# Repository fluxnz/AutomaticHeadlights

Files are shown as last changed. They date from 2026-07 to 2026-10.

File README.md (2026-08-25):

# Automatic Headlights (Arduino Nano)

Automatic headlight controller for an Arduino Nano using a BH1750 ambient light sensor, OLED status display, manual override switch, and relay output.

## Features

- Automatic relay control from ambient light (lux)
- Potentiometer-adjustable AUTO threshold (`0` to `400` lux)
- Hysteresis plus ON/OFF delay to prevent relay chatter
- Fail-safe behavior:
  - Relay stays OFF if the BH1750 sensor fails to initialize or returns an invalid reading
  - Relay logic continues even if the OLED is disconnected or unavailable
- Manual override with SPDT center-off switch:
  - Force ON
  - AUTO (center)
  - Force OFF
- OLED UI with day/night icon and live values:
  - Mode (`AUTO` / `FORCE ON` / `FORCE OFF`)
  - `LUX` (live measured light)
  - `SET` (potentiometer threshold)
  - `LIGHT` (`ON` / `OFF` badge)

## Hardware

- Arduino Nano V3 USB-C (ATmega328PB)
- BH1750 GY-302 I2C light sensor
- SSD1306 0.96" OLED 128x64 I2C display
- 10k linear potentiometer (B10K)
- SPDT center-off toggle switch (ON-OFF-ON)
- 5V 1-channel relay module (SRD-05VDC-SL-C)
- 470uF electrolytic capacitor
- 100nF ceramic capacitor

## Wiring

### I2C bus

- Nano `A4` -> BH1750 `SDA` and OLED `SDA`
- Nano `A5` -> BH1750 `SCL` and OLED `SCL`
- Nano `5V` -> sensor/display `VCC`
- Nano `GND` -> sensor/display `GND`

### Inputs and output

- Potentiometer wiper -> Nano `A0`
- Pot ends -> `5V` and `GND`
- Relay input -> Nano `D8`
- Toggle switch common -> `GND`
- Toggle throw 1 -> Nano `D2` (force ON)
- Toggle throw 2 -> Nano `D3` (force OFF)
- Handbrake wire -> Nano `D4`
- Vehicle ground -> Nano `GND`

The sketch uses `INPUT_PULLUP` for the switch pins, so active switch position pulls pin `LOW`.
The handbrake input also uses `INPUT_PULLUP`, so when the handbrake wire is earthed, `D4` reads `LOW` (handbrake ON).

## Capacitor placement (recommended)

- `100nF` ceramic close to Nano `5V/GND`
- `470uF` electrolytic across `5V/GND` rail to absorb relay/supply transients

## Arduino sketch location

- `Sketch/AutomaticHeadlights/AutomaticHeadlights.ino`

## Required libraries

Install these libraries in Arduino IDE / Arduino CLI:

- `BH1750`
- `U8g2`

## Build and upload

1. Open `Sketch/AutomaticHeadlights/AutomaticHeadlights.ino` in Arduino IDE.
2. Select board: **Arduino Nano**.
3. Select the correct processor/bootloader settings for your Nano clone/original.
4. Select the correct COM port.
5. Compile and upload.

## Runtime behavior

- AUTO mode maps potentiometer value (`0-1023`) to `0-400` lux setpoint.
- Relay switches ON only after sustained darkness (`AUTO_ON_DELAY_MS`).
- Relay switches OFF only after sustained brightness (`AUTO_OFF_DELAY_MS`).
- Hysteresis (`HYSTERESIS_LUX`) prevents flicker near threshold.
- If the BH1750 sensor is unavailable or returns a bad reading, the sketch forces the relay OFF and disables AUTO control until reset.
- If the handbrake is ON (earthed input on `D4`), the sketch forces the relay OFF in all modes (AUTO / FORCE ON / FORCE OFF).
- Display rendering uses U8g2 page buffering (`_1_` constructor variant).

### Display example

AUTO  
Lux: 18 lx  
Set: 40 lx  
Brake: ON  
Light: OFF

## Safety note

This project is intended to switch a relay control signal. If you are switching vehicle lighting power, use proper automotive wiring practices (fusing, suitable wire gauge, and protected enclosures).

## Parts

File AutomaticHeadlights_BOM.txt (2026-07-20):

Arduino Nano
BH1750 GY-302 I2C Light Sensor Module
SSD1306 0.96" OLED 128x64 I2C Display
10k Linear Potentiometer (B10K)
SPDT Centre-Off Toggle Switch (ON-OFF-ON)
5V 1-Channel Relay Module (SRD-05VDC-SL-C)
470µF 16V Electrolytic Capacitor
100nF Ceramic Capacitor

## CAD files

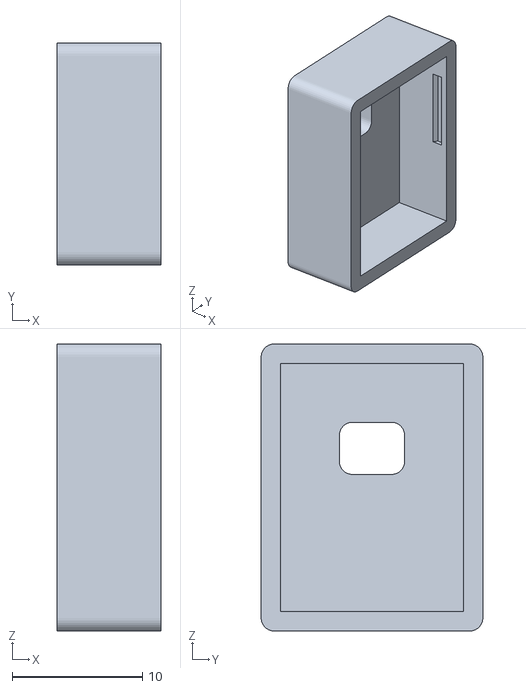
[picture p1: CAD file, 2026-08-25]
BH1750_Case_Base.stl
8.00 x 17.0 x 22.0

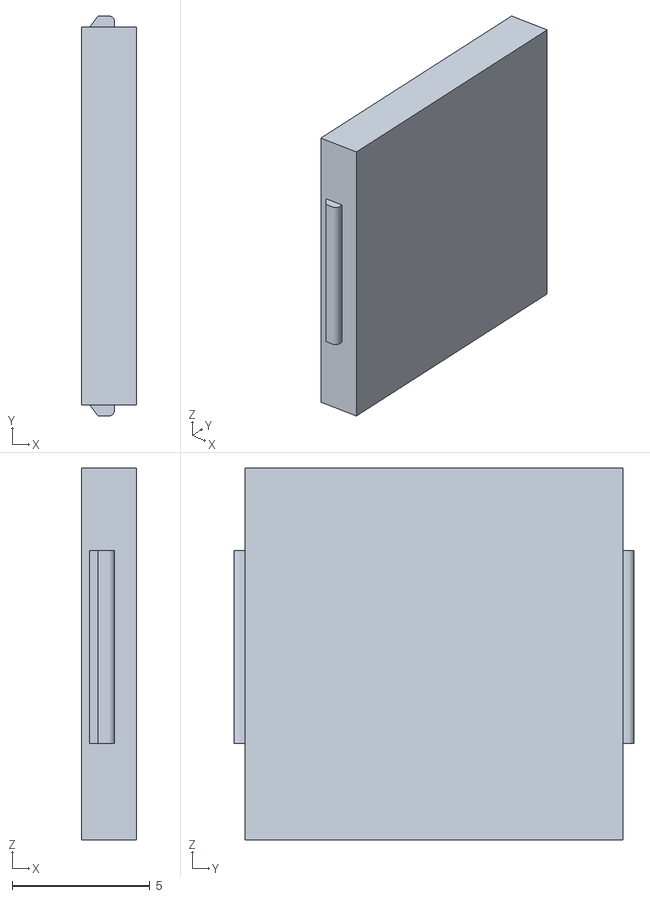
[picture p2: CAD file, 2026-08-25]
BH1750_Case_Base_Lid.stl
2.00 x 14.5 x 13.5

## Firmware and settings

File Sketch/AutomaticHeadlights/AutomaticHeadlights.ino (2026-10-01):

#include <Wire.h>
#include <BH1750.h>
#include <U8g2lib.h>

// -------- Hardware configuration --------
static const uint8_t PIN_RELAY = 8;
static const uint8_t PIN_POT = A0;
static const uint8_t PIN_SWITCH_FORCE_ON = 2;
static const uint8_t PIN_SWITCH_FORCE_OFF = 3;
static const uint8_t PIN_HANDBRAKE = 4;

// Most 5V relay modules are active LOW. Set false if your module is active HIGH.
static const bool RELAY_ACTIVE_LOW = true;

// OLED (128x64, I2C)
U8G2_SSD1306_128X64_NONAME_1_HW_I2C display(U8G2_R0);

BH1750 lightMeter;

enum ControlMode {
	MODE_AUTO,
	MODE_FORCE_ON,
	MODE_FORCE_OFF
};

float currentLux = 0.0f;
float filteredLux = 0.0f;
bool relayClosed = false;  // Closed = headlights ON.
bool displayReady = false;
bool sensorReady = false;
bool hasLuxSample = false;

unsigned long lastSensorReadMs = 0;
unsigned long lastDisplayRefreshMs = 0;
unsigned long darkCandidateStartMs = 0;
unsigned long brightCandidateStartMs = 0;
unsigned long lastSensorReinitAttemptMs = 0;
unsigned long lastI2cRecoveryMs = 0;
uint8_t consecutiveSensorErrors = 0;

static const uint16_t SENSOR_INTERVAL_MS = 200;
static const uint16_t DISPLAY_INTERVAL_MS = 120;
static const uint16_t AUTO_ON_DELAY_MS = 2500;
static const uint16_t AUTO_OFF_DELAY_MS = 4000;
static const uint16_t SENSOR_REINIT_INTERVAL_MS = 1500;
static const uint16_t I2C_RECOVERY_INTERVAL_MS = 10000;
static const uint8_t MAX_SENSOR_ERRORS_BEFORE_FAULT = 5;

// Map potentiometer (0..1023) to an easy-to-tune AUTO trigger range.
// Left 0 lx (very dark), center ~200 lx, right 400 lx.
static const float THRESHOLD_MIN_LUX = 0.0f;
static const float THRESHOLD_MAX_LUX = 400.0f;

// Hysteresis band to avoid relay chatter around threshold.
static const float HYSTERESIS_LUX = 35.0f;

// BH1750 high-res mode tops out well below this; anything above is a bad reading.
static const float MAX_VALID_LUX = 60000.0f;

void resetAutoTimers() {
	darkCandidateStartMs = 0;
	brightCandidateStartMs = 0;
}

void forceRelayOpenAndReset() {
	writeRelay(false);
	resetAutoTimers();
}

void writeRelay(bool closed) {
	relayClosed = closed;
	uint8_t pinState;
	if (RELAY_ACTIVE_LOW) {
		pinState = closed ? LOW : HIGH;
	} else {
		pinState = closed ? HIGH : LOW;
	}
	digitalWrite(PIN_RELAY, pinState);
}

ControlMode readModeFromSwitch() {
	// Switch expected wiring:
	// - Common to GND
	// - One throw to D2 (force ON), other throw to D3 (force OFF)
	// - Center OFF leaves both pins HIGH via INPUT_PULLUP
	bool forceOnActive = digitalRead(PIN_SWITCH_FORCE_ON) == LOW;
	bool forceOffActive = digitalRead(PIN_SWITCH_FORCE_OFF) == LOW;

	if (forceOnActive && !forceOffActive) {
		return MODE_FORCE_ON;
	}
	if (forceOffActive && !forceOnActive) {
		return MODE_FORCE_OFF;
	}
	return MODE_AUTO;
}

bool isHandbrakeOn() {
	// Handbrake wire is expected to be earthed when engaged.
	// With INPUT_PULLUP, LOW means handbrake ON.
	return digitalRead(PIN_HANDBRAKE) == LOW;
}

float readThresholdFromPot() {
	int pot = analogRead(PIN_POT);
	return THRESHOLD_MIN_LUX +
				 (THRESHOLD_MAX_LUX - THRESHOLD_MIN_LUX) * (static_cast<float>(pot) / 1023.0f);
}

void updateAutoRelayWithDelay(unsigned long now, float thresholdLux) {
	float onTriggerLux = thresholdLux - HYSTERESIS_LUX;
	float offTriggerLux = thresholdLux + HYSTERESIS_LUX;
	if (onTriggerLux < 0.0f) {
		onTriggerLux = 0.0f;
	}

	if (!relayClosed) {
		// Open relay (lights OFF): require sustained dark before turning ON.
		if (currentLux < onTriggerLux) {
			if (darkCandidateStartMs == 0) {
				darkCandidateStartMs = now;
			}
			if (now - darkCandidateStartMs >= AUTO_ON_DELAY_MS) {
				writeRelay(true);
				darkCandidateStartMs = 0;
			}
		} else {
			darkCandidateStartMs = 0;
		}
		brightCandidateStartMs = 0;
	} else {
		// Closed relay (lights ON): require sustained bright before turning OFF.
		if (currentLux > offTriggerLux) {
			if (brightCandidateStartMs == 0) {
				brightCandidateStartMs = now;
			}
			if (now - brightCandidateStartMs >= AUTO_OFF_DELAY_MS) {
				writeRelay(false);
				brightCandidateStartMs = 0;
			}
		} else {
			brightCandidateStartMs = 0;
		}
		darkCandidateStartMs = 0;
	}
}

void drawSunIcon(int16_t cx, int16_t cy) {
	display.setDrawColor(1);
	display.drawDisc(cx, cy, 7);
	display.setDrawColor(0);
	display.drawDisc(cx, cy, 4);
	display.setDrawColor(1);
	for (uint8_t i = 0; i < 8; i++) {
		float a = i * 0.785398f;  // 2*pi/8
		int16_t x0 = cx + static_cast<int16_t>(9 * cos(a));
		int16_t y0 = cy + static_cast<int16_t>(9 * sin(a));
		int16_t x1 = cx + static_cast<int16_t>(13 * cos(a));
		int16_t y1 = cy + static_cast<int16_t>(13 * sin(a));
		display.drawLine(x0, y0, x1, y1);
	}
}

void drawMoonIcon(int16_t cx, int16_t cy) {
	display.setDrawColor(1);
	display.drawDisc(cx, cy, 8);
	display.setDrawColor(0);
	display.drawDisc(cx + 4, cy - 2, 8);
	display.setDrawColor(1);
}

void drawUi(ControlMode mode, float thresholdLux) {
	bool handbrakeOn = isHandbrakeOn();
	display.firstPage();
	do {
		display.setDrawColor(1);
		display.setFont(u8g2_font_7x13B_tf);

		display.setCursor(0, 12);
		// Keep the active mode visible, and show brake status separately below.
		if (mode == MODE_FORCE_ON) {
			display.println(F("FORCE ON"));
		} else if (mode == MODE_FORCE_OFF) {
			display.println(F("FORCE OFF"));
		} else {
			display.println(F("AUTO"));
		}
		display.drawHLine(0, 14, 128);

		display.setFont(u8g2_font_6x12_tf);
		display.setCursor(0, 25);
		display.print(F("Lux: "));
		if (sensorReady) {
			float displayLux = constrain(currentLux, 0.0f, 32767.0f);
			display.print(static_cast<int>(displayLux + 0.5f));
			display.print(F(" lx"));
		} else {
			display.print(F("ERR"));
		}

		display.setCursor(0, 37);
		display.print(F("Set: "));
		display.print(static_cast<int>(thresholdLux + 0.5f));
		display.print(F(" lx"));

		display.setCursor(0, 49);
		display.print(F("Brake: "));
		display.print(handbrakeOn ? F("ON") : F("OFF"));

		display.setCursor(0, 61);
		display.print(F("Light: "));
		display.print(relayClosed ? F("ON") : F("OFF"));

		bool darkNow = currentLux < thresholdLux;
		if (darkNow) {
			drawMoonIcon(108, 34);
		} else {
			drawSunIcon(108, 34);
		}
	} while (display.nextPage());
}

void setup() {
	pinMode(PIN_RELAY, OUTPUT);
	pinMode(PIN_SWITCH_FORCE_ON, INPUT_PULLUP);
	pinMode(PIN_SWITCH_FORCE_OFF, INPUT_PULLUP);
	pinMode(PIN_HANDBRAKE, INPUT_PULLUP);

	// Fail-safe default: relay open at startup.
	forceRelayOpenAndReset();

	Wire.begin();
	// Prevent an I2C glitch from hanging the sketch forever.
	Wire.setWireTimeout(25000, true);
	sensorReady = lightMeter.begin(BH1750::CONTINUOUS_HIGH_RES_MODE);
	consecutiveSensorErrors = sensorReady ? 0 : MAX_SENSOR_ERRORS_BEFORE_FAULT;

	// U8g2 does not provide a simple init-fail status; begin and continue.
	display.begin();
	displayReady = true;
	display.firstPage();
	do {
		display.setDrawColor(1);
		display.setFont(u8g2_font_7x13B_tf);
		int16_t titleX = (128 - display.getStrWidth("Auto Headlights")) / 2;
		display.setCursor(titleX, 24);
		display.println(F("Auto Headlights"));
		display.setFont(u8g2_font_6x12_tf);
		int16_t initX = (128 - display.getStrWidth("Init...")) / 2;
		display.setCursor(initX, 42);
		display.println(F("Init..."));
	} while (display.nextPage());
}

void recoverI2cDevices() {
	// A short car supply glitch can leave I2C devices or the AVR bus in a bad state.
	// Reinitialize both devices periodically so the controller can recover without a power cycle.
	Wire.end();
	pinMode(A4, INPUT_PULLUP);
	pinMode(A5, INPUT_PULLUP);
	delay(10);
	Wire.begin();
	Wire.setWireTimeout(25000, true);

	sensorReady = lightMeter.begin(BH1750::CONTINUOUS_HIGH_RES_MODE);
	consecutiveSensorErrors = sensorReady ? 0 : MAX_SENSOR_ERRORS_BEFORE_FAULT;
	hasLuxSample = false;

	display.begin();
	displayReady = true;
}

void loop() {
	unsigned long now = millis();

	if (now - lastSensorReadMs >= SENSOR_INTERVAL_MS) {
		lastSensorReadMs = now;

		if (sensorReady) {
			float rawLux = lightMeter.readLightLevel();
			if (rawLux < 0.0f || isnan(rawLux) || isinf(rawLux) || rawLux > MAX_VALID_LUX) {
				if (consecutiveSensorErrors < 255) {
					consecutiveSensorErrors++;
				}
				if (consecutiveSensorErrors >= MAX_SENSOR_ERRORS_BEFORE_FAULT) {
					sensorReady = false;
					hasLuxSample = false;
					forceRelayOpenAndReset();
				}
			} else {
				consecutiveSensorErrors = 0;
				if (!hasLuxSample) {
					filteredLux = rawLux;
					hasLuxSample = true;
				} else {
					// Lightweight smoothing for stable display and control.
					filteredLux = (filteredLux * 0.75f) + (rawLux * 0.25f);
				}
				currentLux = filteredLux;
			}
		} else if (now - lastSensorReinitAttemptMs >= SENSOR_REINIT_INTERVAL_MS) {
			lastSensorReinitAttemptMs = now;
			sensorReady = lightMeter.begin(BH1750::CONTINUOUS_HIGH_RES_MODE);
			if (sensorReady) {
				consecutiveSensorErrors = 0;
				hasLuxSample = false;
			}
		}
	}

	ControlMode mode = readModeFromSwitch();
	float thresholdLux = readThresholdFromPot();
	bool handbrakeOn = isHandbrakeOn();

	if (handbrakeOn) {
		// Safety interlock: handbrake engaged keeps headlights relay open.
		forceRelayOpenAndReset();
	} else if (!sensorReady) {
		forceRelayOpenAndReset();
	} else if (mode == MODE_FORCE_ON) {
		writeRelay(true);
		resetAutoTimers();
	} else if (mode == MODE_FORCE_OFF) {
		forceRelayOpenAndReset();
	} else {
		updateAutoRelayWithDelay(now, thresholdLux);
	}

	if (!sensorReady && (now - lastI2cRecoveryMs >= I2C_RECOVERY_INTERVAL_MS)) {
		lastI2cRecoveryMs = now;
		recoverI2cDevices();
	}

	if (displayReady && (now - lastDisplayRefreshMs >= DISPLAY_INTERVAL_MS)) {
		lastDisplayRefreshMs = now;
		drawUi(mode, thresholdLux);
	}
}

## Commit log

2026-07-20 Add sensor fail-safe and update docs
    [AutomaticHeadlights.ino]
2026-07-21 Switch OLED to U8g2 and refresh README
2026-08-25 Update project files
    [BH1750_Case_Base.stl, BH1750_Case_Base_Lid.stl]
2026-10-01 Improve sensor fault recovery
